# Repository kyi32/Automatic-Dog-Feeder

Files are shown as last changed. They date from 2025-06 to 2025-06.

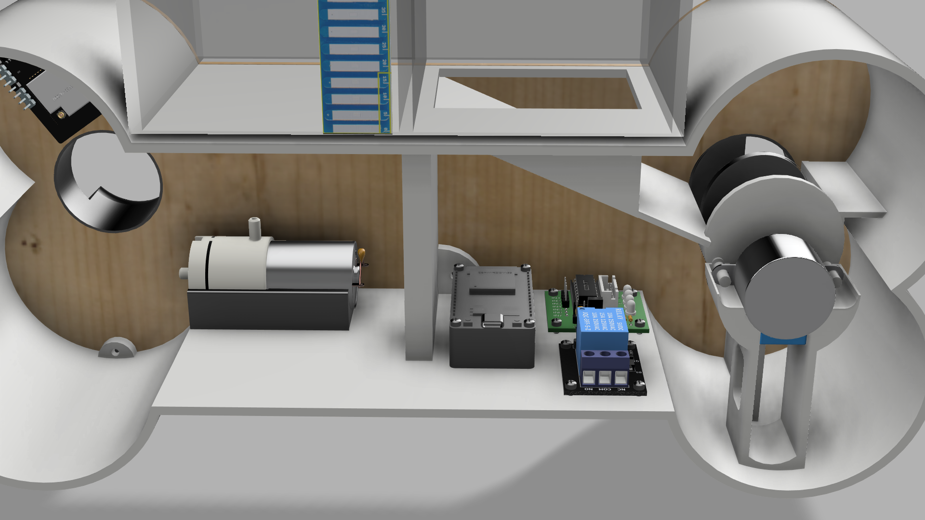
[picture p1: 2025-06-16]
assemblypetfeeder v6.png

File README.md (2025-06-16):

# Project of the Automatic Pet Feeder

## Overview
This repository contains the design files, documentation, and code for an automatic pet feeder developed by a team from the Faculty of Mechanical Engineering and Robotics at AGH. The project features a smart, app-controlled feeder with video monitoring, sensor-based food and water level detection, and customizable feeding schedules, prioritizing sustainability with recyclable materials.

## Files
### 3D Models and Drawings
- `BACK_plate.f3d`: Back plate component.
- `Bone_back_plate(autocad).pdf`: AutoCAD drawing of the back plate.
- `Bone_container_2(autocad).pdf`: AutoCAD drawing of the bone container.
- `Bone_shaped_container(autocad).pdf`: AutoCAD drawing of the bone-shaped container.
- `Bonefront_plateContainer(autocad).pdf`: AutoCAD drawing of the front plate and container.
- `Container(autocad).pdf`: AutoCAD drawing of the container.
- `Container_Drawing_v1.pdf`: Container drawing version 1.
- `Container.f3d`: Container component.
- `FOOD_SLEEVE.f3d`: Food sleeve component.
- `Front_plate.f3d`: Front plate component.
- `PetFeederAssembly.pdf`: Assembly drawing of the pet feeder.
- `PetFeederExplosion.pdf`: Exploded view of the pet feeder.
- `WATER_SLEEVE.f3d`: Water sleeve component.
- `assemblyPetfeeder_v6.png`: Assembly image version 6.
- `assemblyPetfeeder_v7.png`: Assembly image version 7.
- `assemblyPetfeeder_v8.f3z`: Assembly file version 8.
- `bone_shapeside_part-1.f3d`: Bone shape side part 1.
- `bone_shapeside_part-2.f3d`: Bone shape side part 2.
- `circuit(1).png`: Circuit diagram image 1.
- `circuit_image(1).png`: Circuit diagram image 2.
- `feedscrew_v1.f3d`: Feed screw component version 1.
- `screw(autocad).pdf`: AutoCAD drawing of the screw.

### Documentation
- `Project of the Automatic Pet Feeder.pdf`: Detailed report including project goals, morphological analysis, core design, system overview, components, software, demonstration, and future improvements.

## Project Details
- **Objective**: Simplify pet care routines with remote monitoring and control, using sustainable materials for small to medium-sized pets.
- **Features**: App-controlled food and water dispensing, live video monitoring, ultrasonic and water level sensors, customizable schedules.
- **Components**: ESP32-S3, Seeed Xiao ESP32-S3 Sense with OV2640 camera, 28BYJ-48 stepper motor, 5-12V DC water pump, HC-SR04 ultrasonic sensor, Grove water sensor, 5V 4A power supply.
- **Materials**: Plywood, biodegradable 3D filament, plexiglass.
- **Power**: 5V 4A power supply with an average current draw of ~2.565A.

## Assembly Instructions
Refer to `PetFeederAssembly.pdf` and `Project of the Automatic Pet Feeder.pdf` for step-by-step assembly instructions, including:
- Laser-cut plywood front and back plates.
- 3D-printed side cylindrical holders and container with plexiglass windows.
- Assembly using screwed and glued joints.

## Software
- **Platform**: Arduino Cloud for remote control, real-time data visualization, and scheduling.
- **Features**: Live sensor data (food/water levels), customizable schedules, manual and scheduled dispensing, camera feed via HTML site.

## Demonstration
- **Videos**: Check the prototype demonstration and assembly 3D model videos at [https://drive.google.com/drive/folders/1KkYPMTIqAwl6N05ESCOF5NJ43y_c4hTv?usp=drive_link](https://drive.google.com/drive/folders/1KkYPMTIqAwl6N05ESCOF5NJ43y_c4hTv?usp=drive_link).

## Contributors
- Ivan Rybalko
- Michal Nowicki
- KyiMin Thant

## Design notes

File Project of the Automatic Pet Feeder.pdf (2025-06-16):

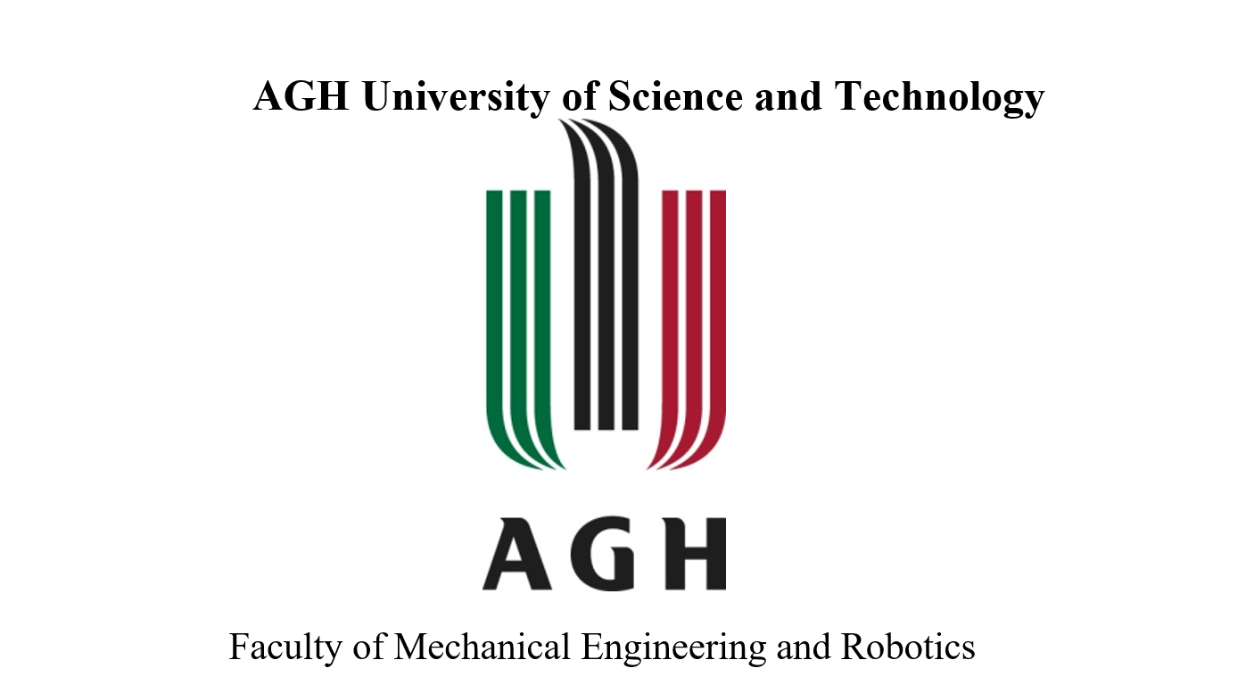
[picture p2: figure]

## Mechatronic Design

## Project of the Automatic Pet Feeder

Team members:

- Ivan Rybalko
- Michał Nowicki
- KyiMin Thant

Summary:

### 1. Introduction and Project Goals

2. Morphological Analysis
2.1 Key Differentiators from Competitors 2.2 Advantages

### 3. Core Design

3.1 Concept
3.2 Drawings

### 4. System Overview and Components

4.1 System Overview
4.2 Components
4.3 Power and Current Consumption

### 5. Software – Arduino Cloud

5.1 Working program code

### 6. System Demonstration and Functional Validation 7. Future Improvements

8. Conclusion

### 1. Introduction and Project Goals

An automatic pet feeder is a device that ensures regular feeding and water supply for a pet without direct human involvement. Our automatic pet feeder offers much more than just a basic timer-based feeder: it is an intelligent system controlled via a mobile application, equipped with video monitoring, sensor-based water and food level detection, and a fully customizable feeding schedule.

Project Goals:

- Simplify pet care routines;
- Provide remote monitoring and control;
- Prioritize sustainability using recyclable materials;

The automatic pet feeder is designed to meet the daily needs of owners of small to medium-sized pets. In modern households, pet owners often face challenges balancing their responsibilities with consistent feeding schedules, proper portion control, and real-time monitoring of their pet’s well-being. This project addresses those challenges by offering a highly automated, connected, and user-friendly solution

### 2. Morphological Analysis

Morphological Analysis Table - Design

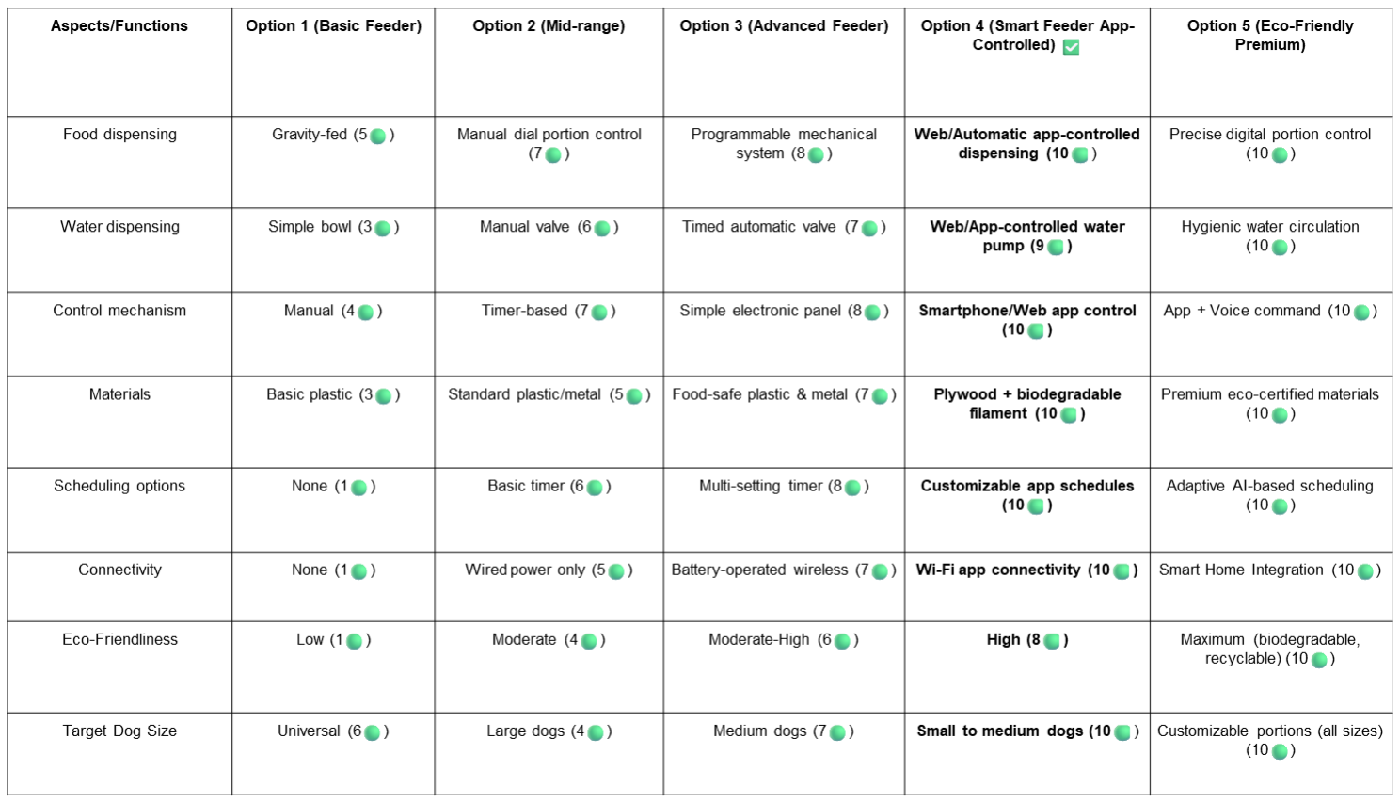
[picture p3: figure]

Functionality (1-10), Price (10-1):

Option 4 offers the best balance of functionality, technology, and value. With app-controlled food and water dispensing, customizable schedules, and Wi-Fi connectivity, it provides smart automation without the premium cost of Option 5. It also uses eco-friendly materials, making it both practical and sustainable. Overall, Option 4 is ideal for modern users seeking convenience, control, and efficiency.

Morphological Analysis Table Electronics

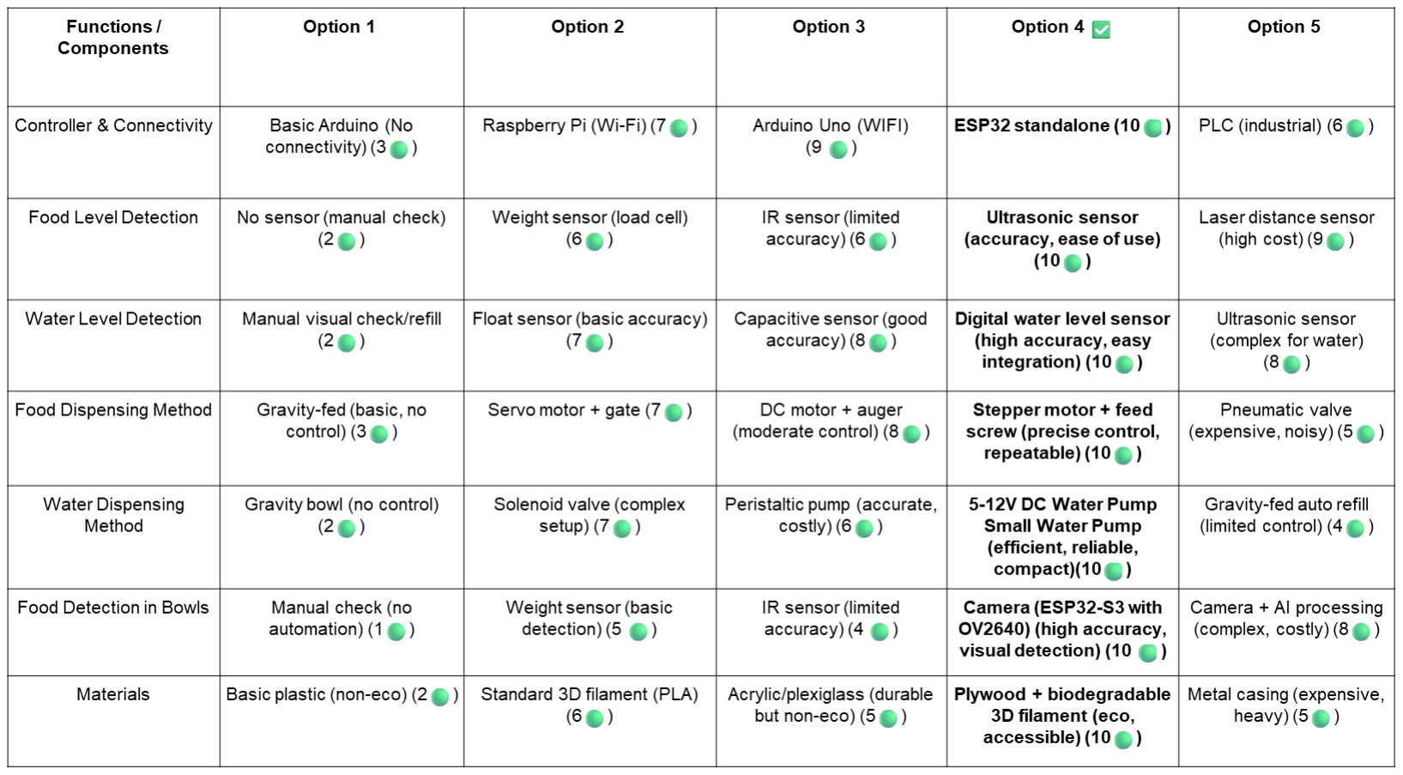
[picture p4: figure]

Functionality (1-10), Price (10-1)

Option 4 stands out by combining high-performance components with smart automation at a reasonable cost. It uses the ESP32 controller for powerful connectivity, ultrasonic sensors for accurate food and water level sensor for water level detection, and stepper motors for precise dispensing making Option 4 the most balanced and advanced choice.

Morphological Analysis Table Mechanical Components

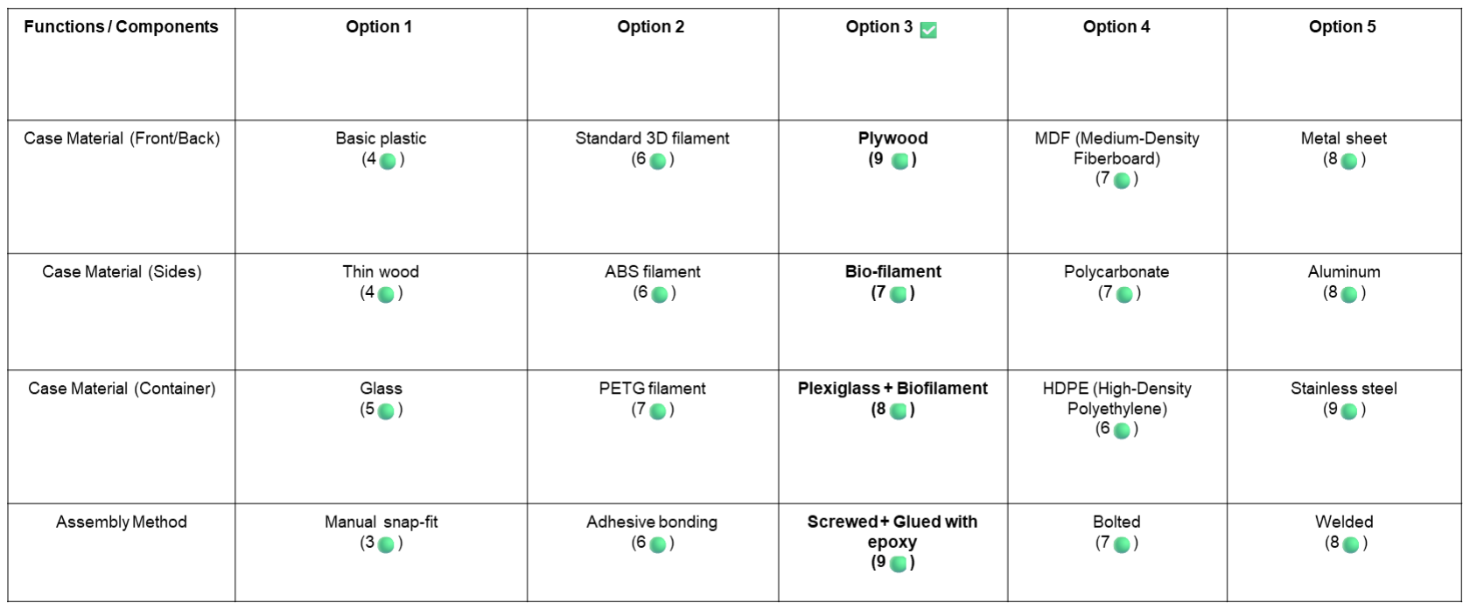
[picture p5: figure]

Functionality (1-10), Price (10-1):

Option 3 offers the most practical and well-balanced mechanical design. It uses plywood for the front/back—strong, versatile, and cost-effective—and bio-filament sides, combining durability with eco-friendliness. The container is made of 3d printed filament with plexiglass windows , offering both strength and visibility. For assembly, it uses screwed and epoxy-glued joints, ensuring strong and reliable construction. This configuration provides a solid balance of durability, sustainability, and moderate cost, making Option 3 the most efficient and well-rounded mechanical solution.

### 2.1 Key Differentiators from Competitors

The automatic pet feeder stands out in a competitive market by offering a balanced blend of intelligent automation, sustainability, and user-centric design. While many feeders on the market offer either mechanical simplicity or app-based scheduling, our solution integrates multiple high-value features into one cohesive and accessible system.

Intelligent Features

- App-Controlled Dispensing : Food delivery is fully automated and triggered through a web or smartphone app interface.
- Water Pump Control : The water pump can also be activated remotely, ensuring pets always have access to fresh water.
- Live Camera Monitoring: Unlike many feeders, ours includes live video streaming via Seeed Xiao ESP32-S3 Sense - with OV2640 camera for real-time supervision.

User-Focused Interface

- Smartphone/Web App Control : The system is designed to be intuitive and fully operable through mobile devices.
- Customizable Schedules : Feeding times and water dispensing are easily programmable, down to the minute.

Eco-Friendly and Durable Construction

- Plywood + Biodegradable Filament : The enclosure is constructed from sustainable materials, prioritizing environmental responsibility without compromising durability.
- Compact and Targeted for Household Pets: Specifically optimized for small to medium-sized dogs

### 2.2 Advantages:

Remote Control and Monitoring: The feeder can be managed entirely via a smartphone or web application. Owners can dispense food or water, view current levels, and even activate a live video stream remotely.
Custom Schedules: Feeding and hydration times can be scheduled in advance, eliminating the risk of missed meals.
Sensor-Based Precision: Ultrasonic and water level sensors provide real-time feedback on how much food and water remains, ensuring pets are never left without resources.
Eco-Friendly Construction: Physical design is made using plywood and biodegradable PLA filament, reducing plastic waste and supporting sustainable practices.

### 3. Core Design

### 3.1 Concept

Concept proposed by the team, combining the best solutions identified during the market review along with justification, pros and cons compared to other solutions, including a simplified schematic of mechanical and electronic components

Dual-Container System: The feeder features a plexiglass container divided into two compartments — one for water, one for dry food. This design enables independent dosing of each resource while providing visual feedback for users to monitor levels.

Screw-Driven Dispensing Mechanism: Dry food is dispensed using a custom-designed feed screw , which is driven by a stepper motor for high precision and repeatability. This ensures consistent portioning without clogging or overfeeding.

Water Pumping System with Relay: A 5-12V DC water pump controlled via a relay module allows for controlled water dispensing. The relay is directly actuated by the ESP32-S3 board without the need for external transistors.

Eco-Friendly Structure: The outer body is built from plywood and biodegradable 3D printed filament. Only the container uses plexiglass for visibility, making the construction sustainable and environmentally friendly.

Cloud Integration (Arduino Cloud): The system uses Arduino Cloud for real-time control and monitoring. Through a smartphone or web app, users can view food/water levels, schedule feeding times, and trigger actions remotely.

Live Video Monitoring:
An Seeed Xiao ESP32-S3 Sense - with OV2640 camera module, connected via Wi-Fi, streams video to a web browser, allowing real-time observation of the pet and food tray. The camera works independently from the ESP32-S3.

Scheduling:
Feeding and watering times can be configured with hour, minute, and date via the dashboard. These settings are stored and processed by the ESP32-S3, which executes the schedule even without an active internet connection.

### 3.2 Drawings

Below is the exploded view of our project – an automatic pet feeder. The design focuses on sustainability, functionality, and ease of manufacturing, as reflected in both the material selection and the production methods used. All parts were designed in CAD software

As illustrated in Figure 1, the feeder consists of five key components, each made from different materials and manufactured using appropriate techniques:

1. Side Cylindrical Holders Parts 1 & 2:
These parts were 3D printed using BIO-filament, a biodegradable and eco-friendly material. BIO-filament was chosen due to its minimal environmental impact and good structural properties The holders provide support for the rotation mechanism that controls the release of food.
2. Front and Back Plates Parts 3 & 4:
These elements were laser-cut from plywood. Plywood is lightweight, affordable, and sustainable, making it ideal for our needs. Laser cutting enabled us to achieve precise shapes and dimensions, including holes and slots necessary for assembly.
3. Food Container Part 6:
The container is made of 3d printed filament with plexiglass windows , chosen for its transparency, light weight, and easy machinability. Transparency allows the user to quickly check the remaining food level. The plexiglass was cut to size and manually assembled using adhesive suitable for acrylic materials.

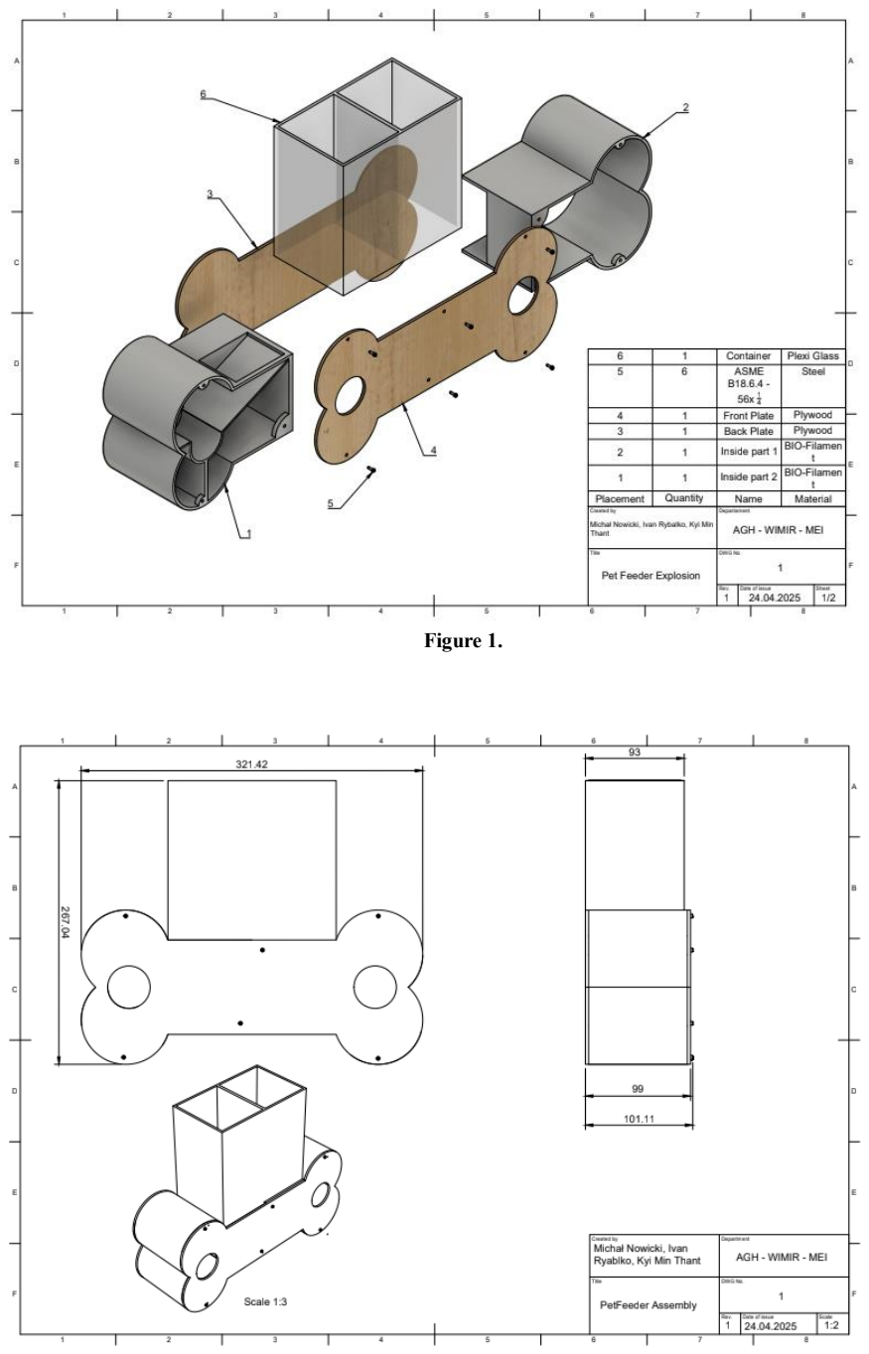
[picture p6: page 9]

Figure 1.

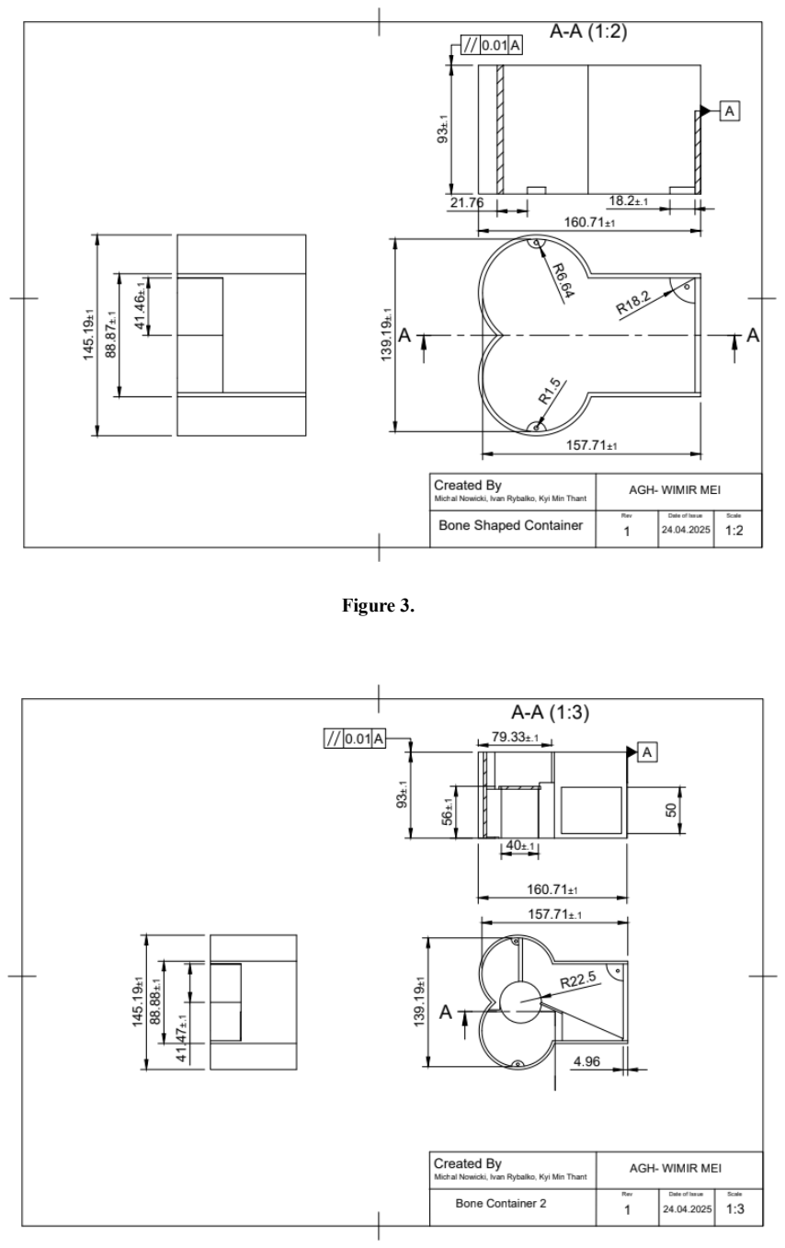
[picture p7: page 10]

Figure 2.

Figure 3.

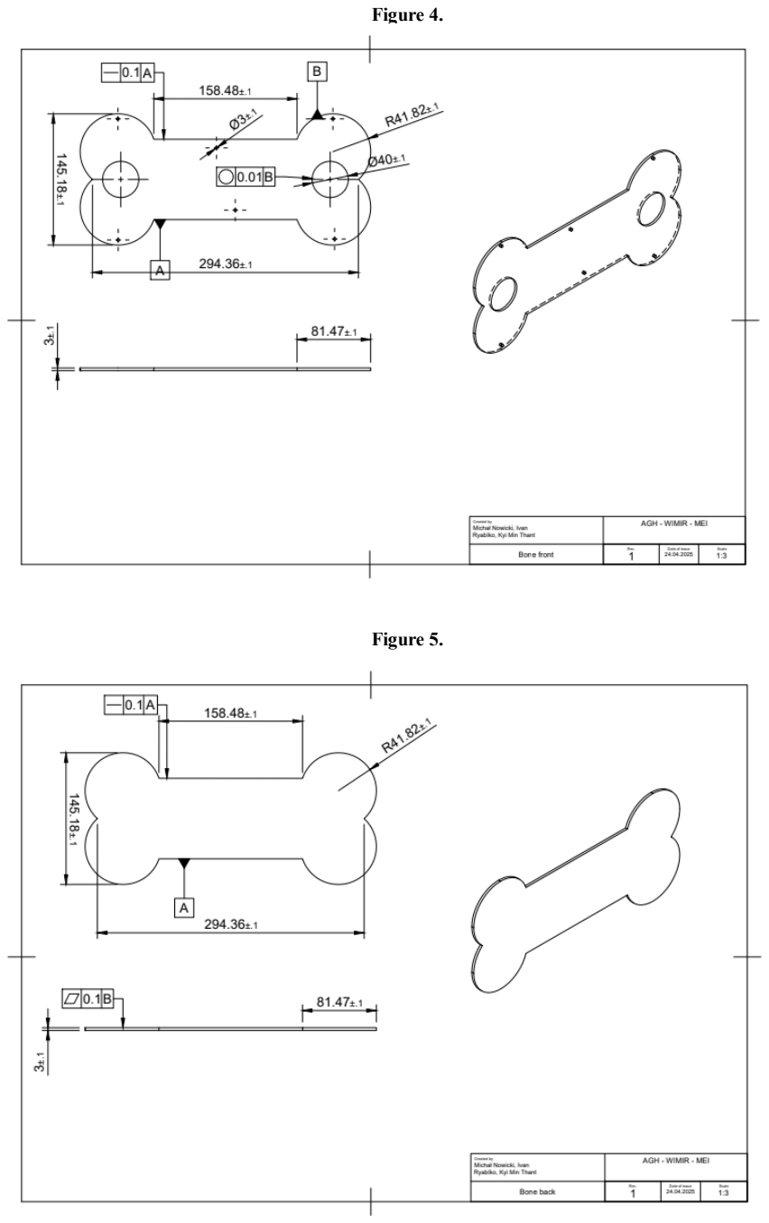
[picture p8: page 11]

Figure 4.

Figure 5.

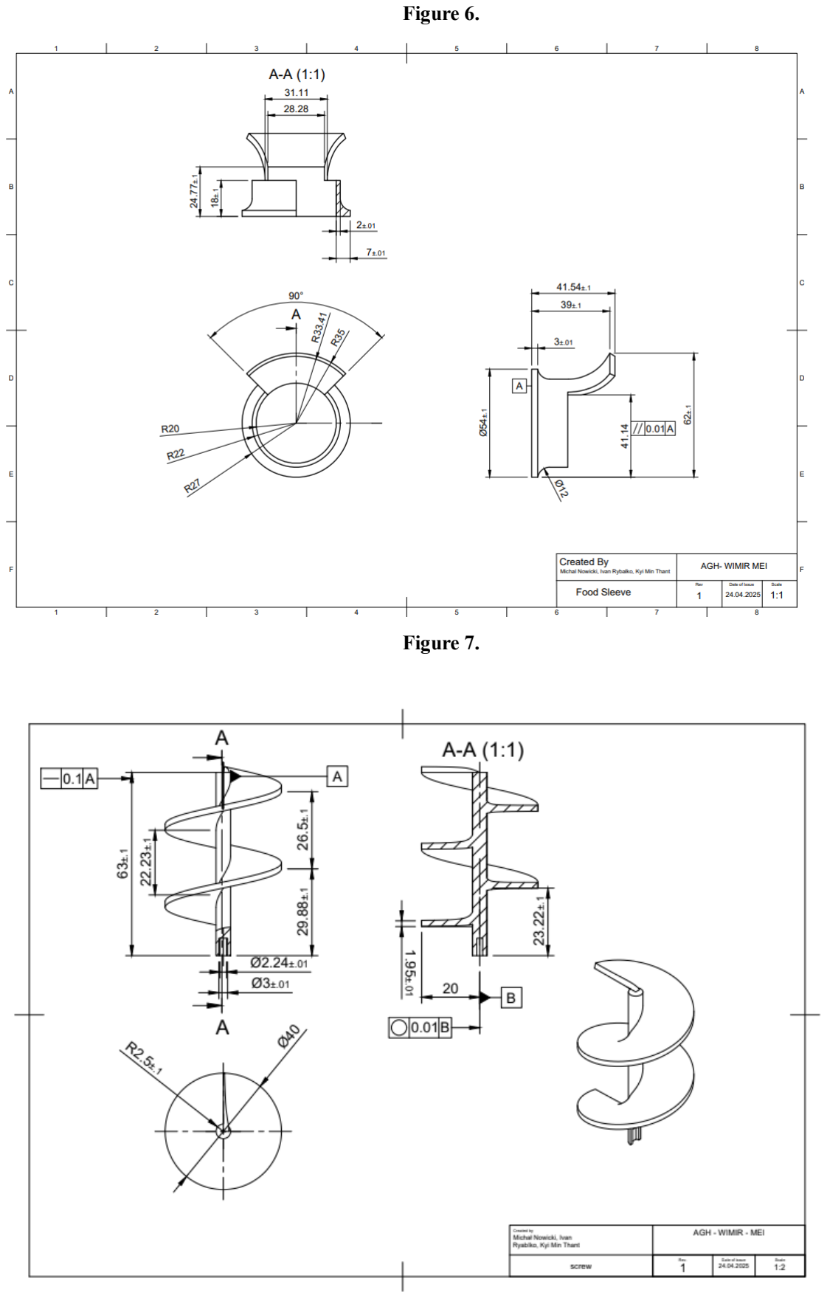
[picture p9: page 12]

Figure 6.

Figure 7.

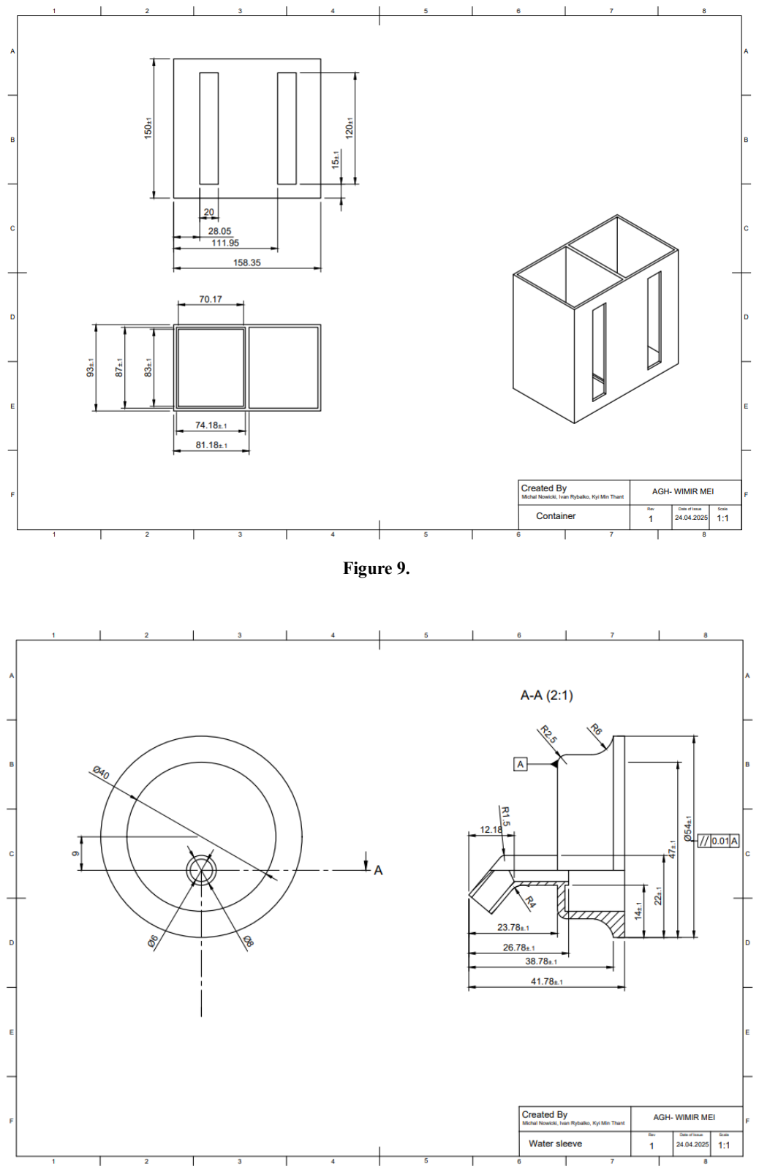
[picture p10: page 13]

Figure 8.

Figure 9.

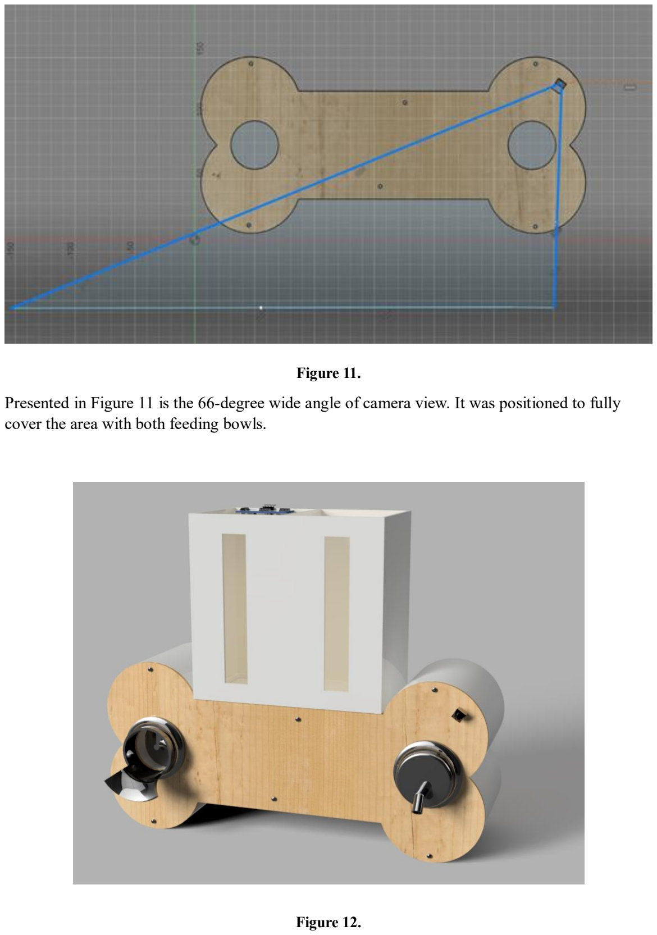
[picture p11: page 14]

Figure 10.

Figure 11.

Presented in Figure 11 is the 66-degree wide angle of camera view. It was positioned to fully cover the area with both feeding bowls.

Figure 12.

In Figure 12, the fully assembled model can be seen, created and visualized in the CAD software. This final assembly view demonstrates how all individual components fit together and provides a clear representation of the functional layout of the pet feeder.

### 4. System Overview and Components

### 4.1 System Overview

The ESP32 board controls and connects to various components,

such as the water level sensor, ultrasonic sensor, stepper motor driver and relay module.

Water level sensor is communicating via SDA(serial DATA Line) and SCL(serial clock line) pins, in reality it looks a bit different that this presented in Figure12 but its connected in correct way.

Whole system is powered by 5V 4A power supply. Estimated current draw of a system is around, 3 Amps.

Relay module is designed to be controlled directly by pins without need of additional transistors.

Seeed Xiao ESP32-S3 Sense - with OV2640 camera is not controlled via main microconstroller. Its streaming image to html site via Wifi and will be accessed by software

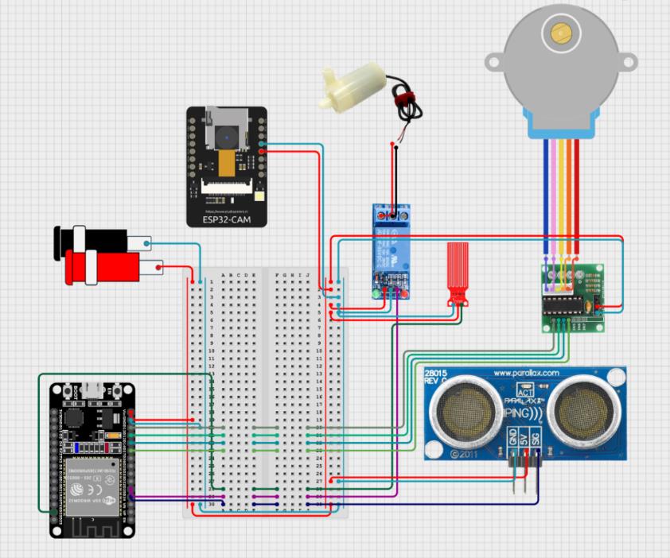
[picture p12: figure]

Figure 13.

### 4.2 Components

Component | Purpose | Justification
ESP32-S3 | Main controller | Powerful, supports Wi-Fi, BLE,
| | I2C

Seeed Xiao ESP32-S3 Sense -
with OV2640 camera | Independent camera module | Easy Wi-Fi HTML streaming
28BYJ-48 + ULN2003 driver Stepper motor for food dosing | Accurate, stable, low-power
5-12V DC Water Pump | Dispenses water | Compact and efficient
Iduino Relay Module | Controls pump power | Simple, works with ESP32
| | directly
HC-SR04 Ultrasonic Sensor | Measures remaining food | Low cost, reliable
Water Level Sensor | Measures water level | High precision, easy I2C
| | integration
5V 4A Power Supply | Powers the full system | Stable enough for ~2.5 A peak
| | load

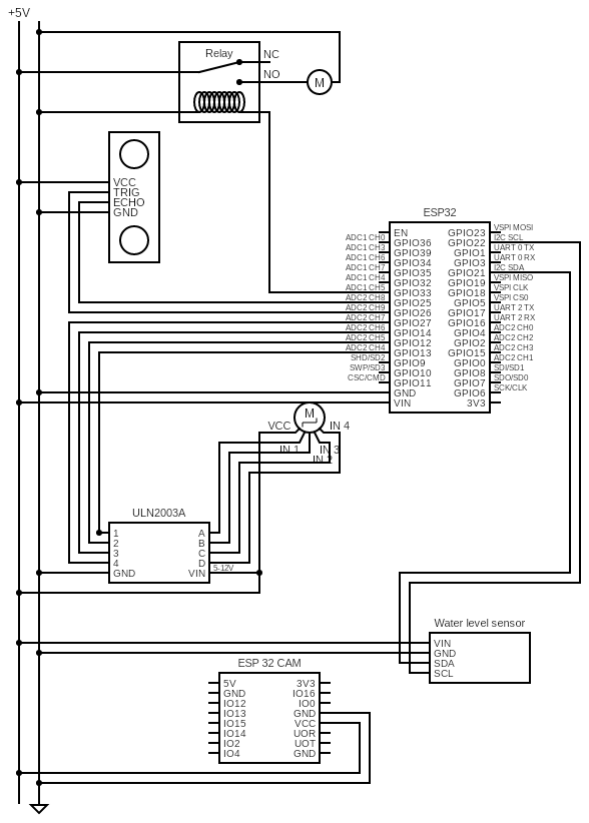
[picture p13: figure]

Figure 14

### 4.3 Power and Current Consumption

The entire system is powered by a 5V 4A switching power supply. Based on our measurements and manufacturer specifications, the average current draw is:

Component | Consumption
ESP32-S3 Sense | 200 mA
Stepper Motor + ULN2003 | 900 + 100 mA
HC-SR04 | 20 mA
Relay Module | 75 mA
Grove Water Sensor | 20 mA

Seeed Xiao ESP32-S3 Sense - with
OV2640 camera | 50 mA
5-12V DC Water Pump | 1200 mA
Total Average | ≈ 2565 mA

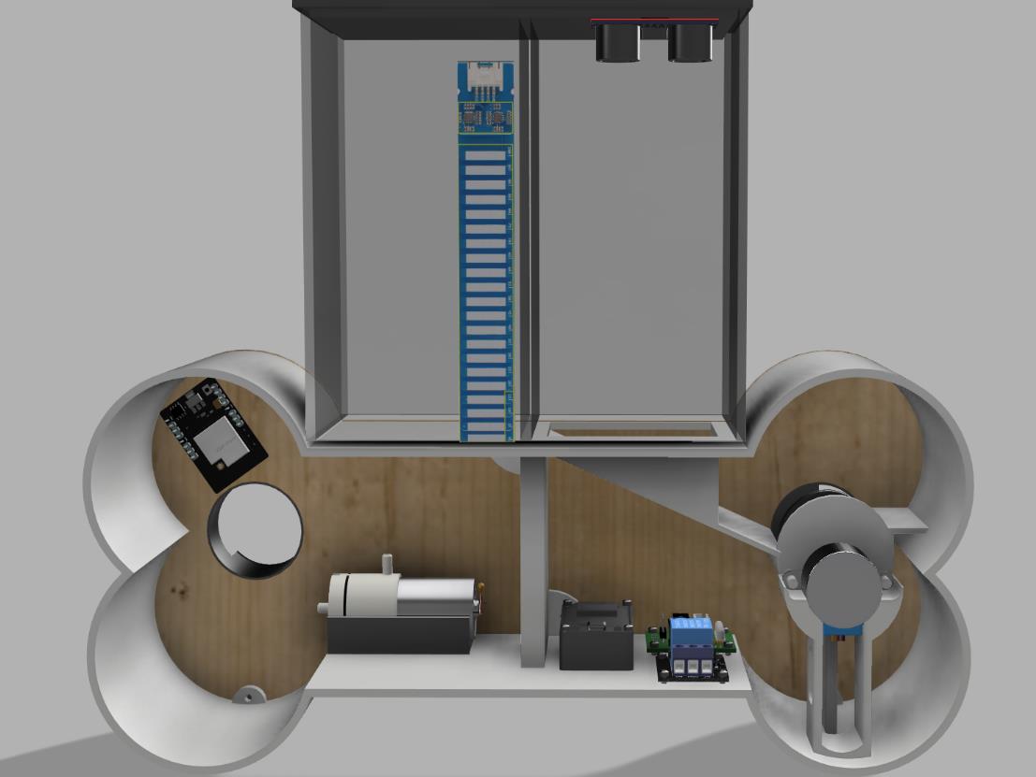
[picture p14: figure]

Figure 15

Figure 15 provides a close-up view. Wires connections are not visible to make the placement more clearly to see. All electrical connections are fully detailed in schemes Figures 13 and 14

### 5. Software – Arduino Cloud

The entire system logic of the automatic pet feeder is implemented using Arduino Cloud, an integrated IoT platform that allows remote device control, real-time data visualization, and scheduling—all accessible through a web dashboard or mobile app.

Cloud Integration Overview

Arduino Cloud handles: Device management (ESP32-S3 Sense); Live synchronization of variables; Scheduling and time-based tasks; User interface rendering (custom dashboard widgets).

System Features and Logic:

Feeding and
Water Dose | Controlled via sliders; values are read by the ESP32-S3 and trigger actuators

Level Monitoring Sensor data (HC-SR04 & Grove Water Sensor) is displayed live in
| dashboard
Schedule
Configuration | User selects hour/minute/date via time picker; stored in cloud and synced
Camera Activation | A dashboard button opens local HTML site with camera image is tunnelled
| through ngrok software to make it available publicly with https protocol

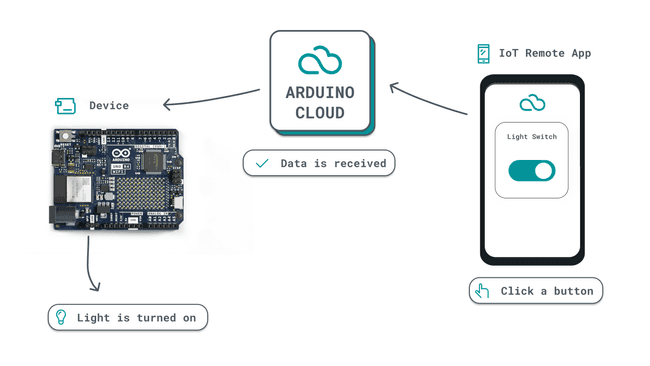
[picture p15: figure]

Figure 16

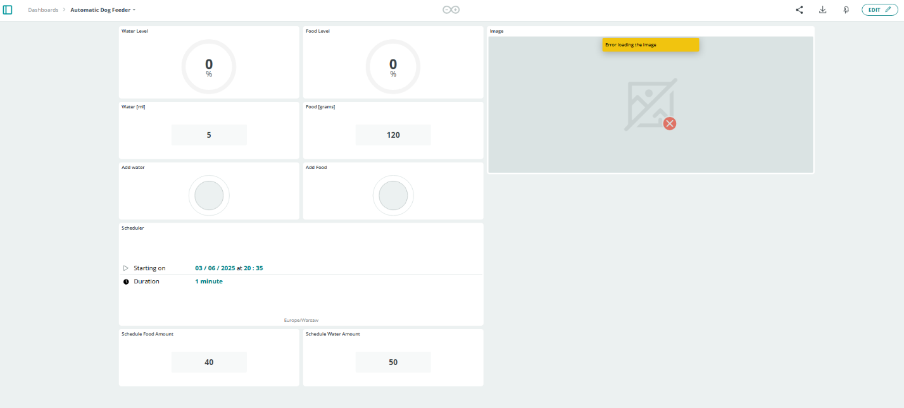
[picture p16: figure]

Figure 17

Figure 17 shows the interface concept developed in Arduino Cloud for controlling the device. This cloud-based dashboard allows real-time monitoring and remote control of key system functions, such as food dispensing, water level status. The interface is designed to be user-friendly and accessible from any internet-connected device.

Cloud Integration

The device connects to the Arduino IoT Cloud using Wi-Fi credentials and unique device keys. Several cloud variables are defined to report water and food levels and to receive user commands and schedules. The initProperties() function registers these variables, enabling seamless communication between the device and cloud dashboard.

Sensor Inputs

Two types of sensors provide environmental feedback:

- Ultrasonic Sensor measures the distance to the food surface, converting it into a percentage with calibration to account for empty bin offset.
- Grove I²C Water Sensor detects the number of “wet” pads across two sections, calculating the water level as a percentage based on active segments.

Actuation

The system dispenses:

- Water via a relay-controlled pump, with timing based on a fixed flow rate (PUMP_FLOW_ML_PER_MIN).
- Food using a stepper motor, where the number of steps is proportional to the required grams (FOOD_PER_REV_G).

Safety and Scheduling

Manual activation is throttled by a 10-second delay to prevent overuse. Additionally, a cloud-based schedule trigger can initiate both food and water dispensing, enabling automated daily routines

### 5.1 Working program code

#include <ArduinoIoTCloud.h> #include <Arduino_ConnectionHandler.h> #include <WiFi.h>

#include <Wire.h>

#include <AccelStepper.h>

const char SSID[] | = "UPC3216837";
const char PASS[] | = "WifiPass";
const char THING_ID[] | = "#############################";
const char DEVICE_LOGIN_NAME[] = "###########################";
const char DEVICE_KEY[] | = "##############################;
WiFiConnectionHandler ArduinoIoTPreferredConnection(SSID, PASS);
#define STEPPER_IN1 | 13

#define STEPPER_IN2 | 12

#define STEPPER_IN3 | 14

#define STEPPER_IN4 | 27

#define TRIG_PIN | 26

#define ECHO_PIN | 25

#define RELAY_PIN | 33

#define I2C_SDA | 21

#define I2C_SCL | 22

const float | PUMP_FLOW_ML_PER_MIN = 1200.0;
const float | FOOD_PER_REV_G | = 20.0;
const float | FOOD_BIN_HEIGHT_CM | = 12.5;
const unsigned long SAFETY_DELAY | = 10000;
const float | FOOD_EMPTY_RAW_PCT | = 7.0;
const float | FOOD_FULL_RANGE_PCT | = 100.0 - FOOD_EMPTY_RAW_PCT;
const uint8_t WATER_LOW_ADDR | = 0x77; | // low-section (8 pads)
const uint8_t WATER_HIGH_ADDR = 0x78; | // high-section (12 pads)
const uint8_t TOUCH_THRESHOLD = 100; | // default threshold for “wet”
float | waterLevelPct, foodLevelPct;
int | waterAmountInput, foodAmountInput;
bool | waterButton, foodButton;
int | scheduleWaterAmount, scheduleFoodAmount;
CloudSchedule | waterScheduleTrigger;

AccelStepper stepper(AccelStepper::HALF4WIRE, STEPPER_IN1, STEPPER_IN3,
STEPPER_IN2, STEPPER_IN4);

unsigned long lastWaterMillis = 0, lastFoodMillis = 0;
bool prevWaterActive = false; void initProperties();
void onWaterButtonChange(); void onFoodButtonChange(); void deployWater(int ml);
void deployFood(int g);
void readI2CWaterSensor(); void setup() {

Serial.begin(115200);
delay(500);
pinMode(TRIG_PIN, OUTPUT); pinMode(ECHO_PIN, INPUT);
pinMode(RELAY_PIN, OUTPUT); digitalWrite(RELAY_PIN, LOW); Wire.begin(I2C_SDA, I2C_SCL); stepper.setMaxSpeed(1000); stepper.setAcceleration(150);
initProperties();

ArduinoCloud.begin(ArduinoIoTPreferredConnection); setDebugMessageLevel(2);
ArduinoCloud.printDebugInfo();
}

void loop() {
ArduinoCloud.update();

static unsigned long lastSensMillis = 0; if (millis() - lastSensMillis > 1000) { lastSensMillis = millis(); readI2CWaterSensor();

digitalWrite(TRIG_PIN, LOW); delayMicroseconds(2);
digitalWrite(TRIG_PIN, HIGH); delayMicroseconds(10);
digitalWrite(TRIG_PIN, LOW);
long dur = pulseIn(ECHO_PIN, HIGH);
float dist = dur * 0.034 / 2.0; // measured distance (cm)
float levelRawCm = FOOD_BIN_HEIGHT_CM - dist;
float rawPct = constrain((levelRawCm / FOOD_BIN_HEIGHT_CM) * 100.0, 0.0, 100.0);
float adjusted | = rawPct - FOOD_EMPTY_RAW_PCT;
float scaledPct | = adjusted * (100.0 / FOOD_FULL_RANGE_PCT);
foodLevelPct | = constrain(scaledPct, 0.0, 100.0);
}
if (waterButton && millis() - lastWaterMillis > SAFETY_DELAY) { deployWater(waterAmountInput);
lastWaterMillis = millis();
}
waterButton = false;
if (foodButton && millis() - lastFoodMillis > SAFETY_DELAY) { deployFood(foodAmountInput);
lastFoodMillis = millis();
}
foodButton = false;
bool nowWaterActive = waterScheduleTrigger.isActive();
if (nowWaterActive && !prevWaterActive) {

Serial.println("Scheduler activated: deploying scheduled water AND food");
deployWater(scheduleWaterAmount); deployFood(scheduleFoodAmount);
}
prevWaterActive = nowWaterActive;
}
void initProperties() {
ArduinoCloud.setBoardId(DEVICE_LOGIN_NAME); ArduinoCloud.setSecretDeviceKey(DEVICE_KEY);

ArduinoCloud.setThingId(THING_ID); ArduinoCloud.addProperty(waterLevelPct, READ, ON_CHANGE, NULL); ArduinoCloud.addProperty(foodLevelPct, READ, ON_CHANGE, NULL); ArduinoCloud.addProperty(waterAmountInput, READWRITE, ON_CHANGE, NULL);
ArduinoCloud.addProperty(foodAmountInput, | READWRITE, ON_CHANGE, NULL);
ArduinoCloud.addProperty(waterButton, | READWRITE, ON_CHANGE,
onWaterButtonChange);
ArduinoCloud.addProperty(foodButton, | READWRITE, ON_CHANGE,
onFoodButtonChange);
ArduinoCloud.addProperty(scheduleWaterAmount, READWRITE, ON_CHANGE, NULL); ArduinoCloud.addProperty(scheduleFoodAmount, READWRITE, ON_CHANGE, NULL); ArduinoCloud.addProperty(waterScheduleTrigger, READWRITE, ON_CHANGE, NULL); }

void onWaterButtonChange() {
if (waterButton && millis() - lastWaterMillis > SAFETY_DELAY) { deployWater(waterAmountInput);
lastWaterMillis = millis();
}
waterButton = false;
}

void onFoodButtonChange() {
if (foodButton && millis() - lastFoodMillis > SAFETY_DELAY) { deployFood(foodAmountInput);
lastFoodMillis = millis();
}
foodButton = false;
}

void readI2CWaterSensor() {
uint8_t low_data[8], high_data[12]; uint32_t mask = 0;

Wire.beginTransmission(WATER_LOW_ADDR); Wire.endTransmission();
Wire.requestFrom(WATER_LOW_ADDR, (uint8_t)8);
for (int i = 0; i < 8 && Wire.available(); i++) { low_data[i] = Wire.read();
if (low_data[i] > TOUCH_THRESHOLD) mask |= 1UL << i; }
Wire.beginTransmission(WATER_HIGH_ADDR); Wire.endTransmission();
Wire.requestFrom(WATER_HIGH_ADDR, (uint8_t)12);
for (int i = 0; i < 12 && Wire.available(); i++) { high_data[i] = Wire.read();
if (high_data[i] > TOUCH_THRESHOLD) mask |= 1UL << (8 + i); }
uint32_t touch = mask;
uint8_t sections = 0;
while (touch & 0x01) {
sections++;
touch >>= 1;
}
waterLevelPct = constrain(sections * 5.0, 0.0, 100.0); }

void deployWater(int ml) {
unsigned long onTime = (unsigned long)(ml / PUMP_FLOW_ML_PER_MIN * 60000.0);
digitalWrite(RELAY_PIN, HIGH);
delay(onTime);
digitalWrite(RELAY_PIN, LOW); }

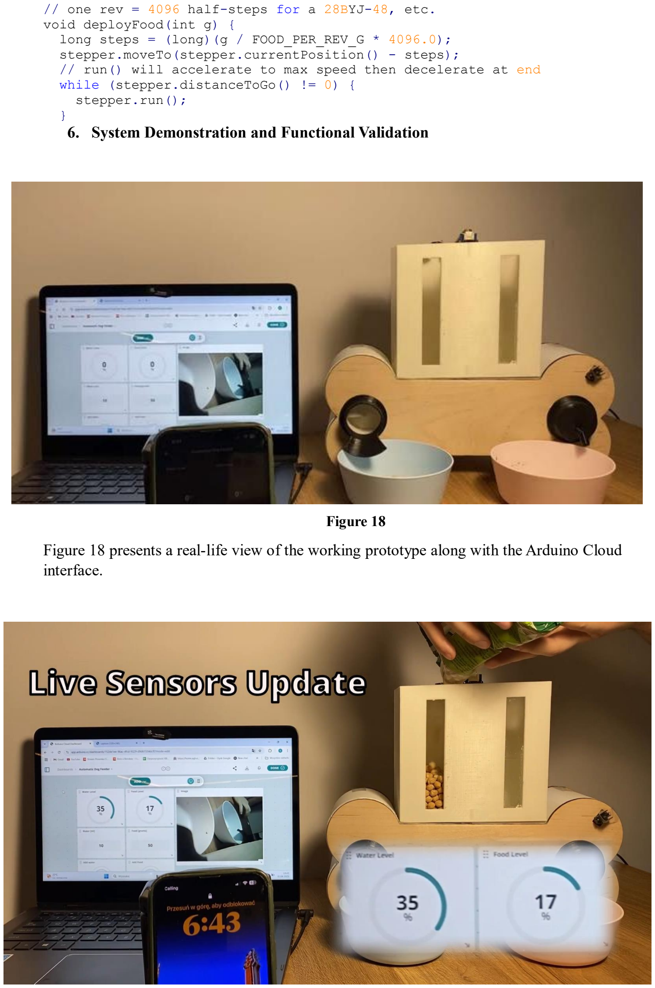
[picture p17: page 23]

// one rev = 4096 half-steps for a 28BYJ-48, etc. void deployFood(int g) {
long steps = (long)(g / FOOD_PER_REV_G * 4096.0); stepper.moveTo(stepper.currentPosition() - steps);
// run() will accelerate to max speed then decelerate at end while (stepper.distanceToGo() != 0) {
stepper.run();
}

### 6. System Demonstration and Functional Validation

Figure 18

Figure 18 presents a real-life view of the working prototype along with the Arduino Cloud interface.

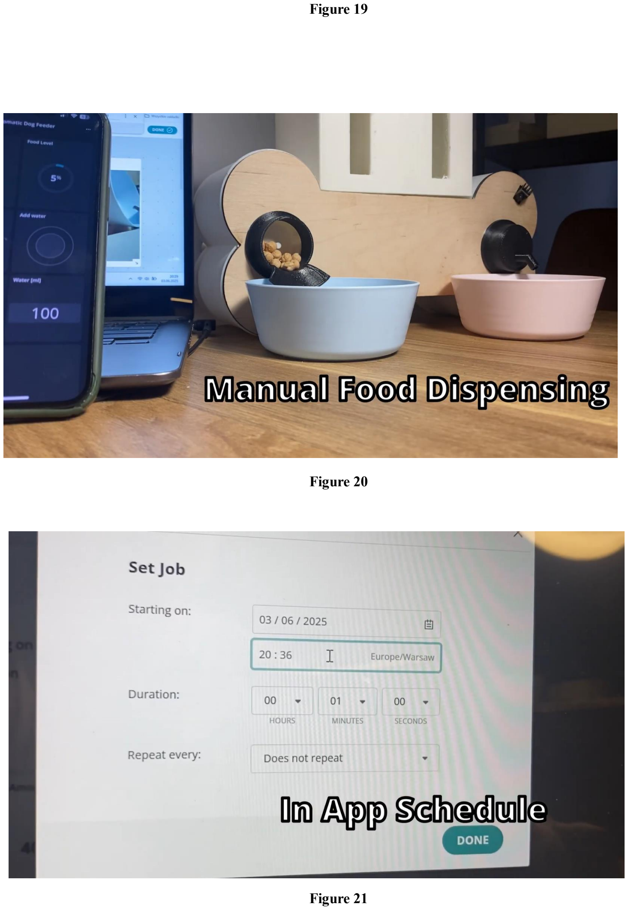
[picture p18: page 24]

Figure 19

Figure 20

Figure 21

Figures 19, 20, 21 demonstrate the working prototype during various stages of operation. For clarity, these images showcase that all previously mentioned functions — including automated food and water dispensing, water level and food level monitoring and camera feedback — operate exactly as intended. This visual documentation confirms the successful implementation and integration of both the hardware and software components.

### 7. Future Improvements

- Physical Control Buttons:
Adding physical buttons on the device would offer direct control without needing to access the online interface, improving accessibility and usability.
- Food Density Adjustment:
Introducing a feature that allows the user to input or select the type and density of pet food would improve the accuracy of portioning by weight rather than volume, making the system more precise for various food types.
- Own Domain and Cloud Hosting:
Hosting the control interface and live camera feed on a custom domain would provide easier and more reliable access. This would allow the user to manage the feeder remotely through a dedicated web application, improving scalability

### 8. Conclusion:

The presented project successfully demonstrates the design, construction, and testing of a automatic pet feeder. Through a combination of CAD modeling, 3D printing, laser cutting, and embedded electronics, the team developed a fully functional prototype capable of automated food and water dispensing, real-time monitoring, and remote control.

As shown in Figures 19–21, the system performs reliably under real conditions. The integration with Arduino Cloud enables intuitive control via a web-based dashboard and mobile devices, offering features such as food and water dispensing, water level and food level monitoring and camera feedback.

The physical prototype, combined with software automation, validates all design goals: sustainability, ease of use, and functionality

Overall, the project proves to be a scalable, practical, and eco-conscious solution for modern pet owners, combining smart-home features with mechatronic engineering principles.

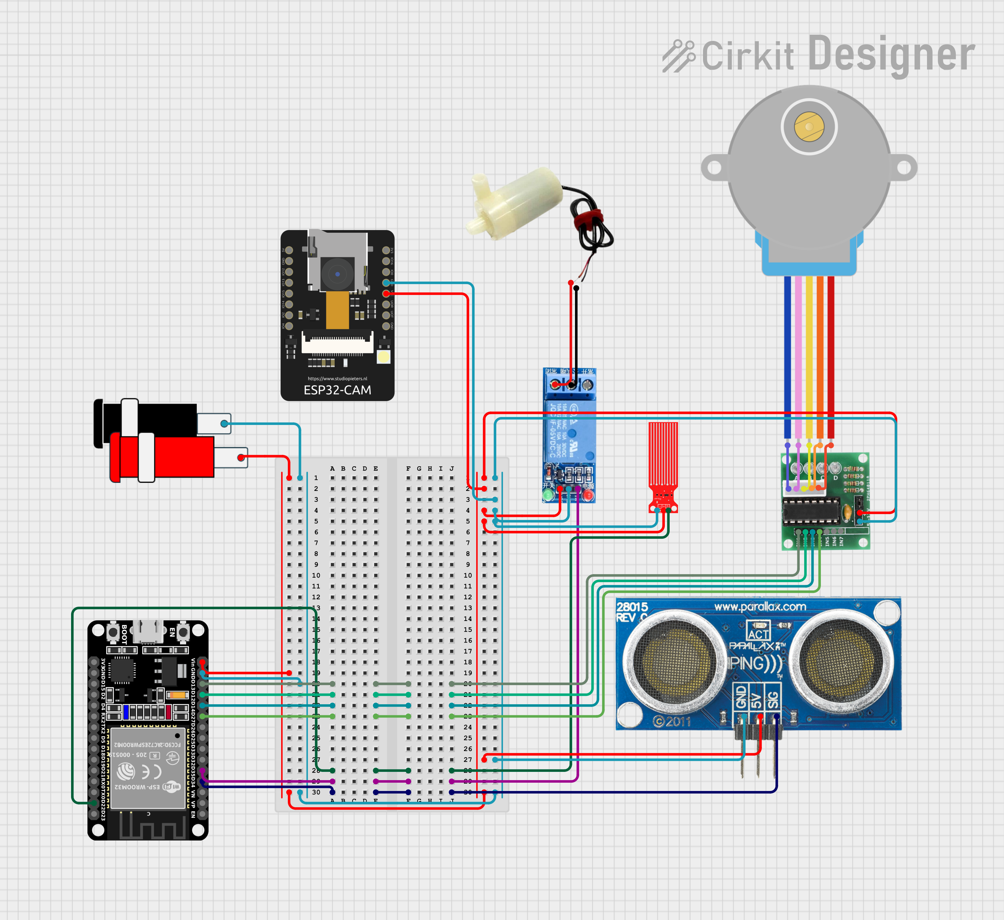
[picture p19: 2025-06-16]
circuit_image (1).png

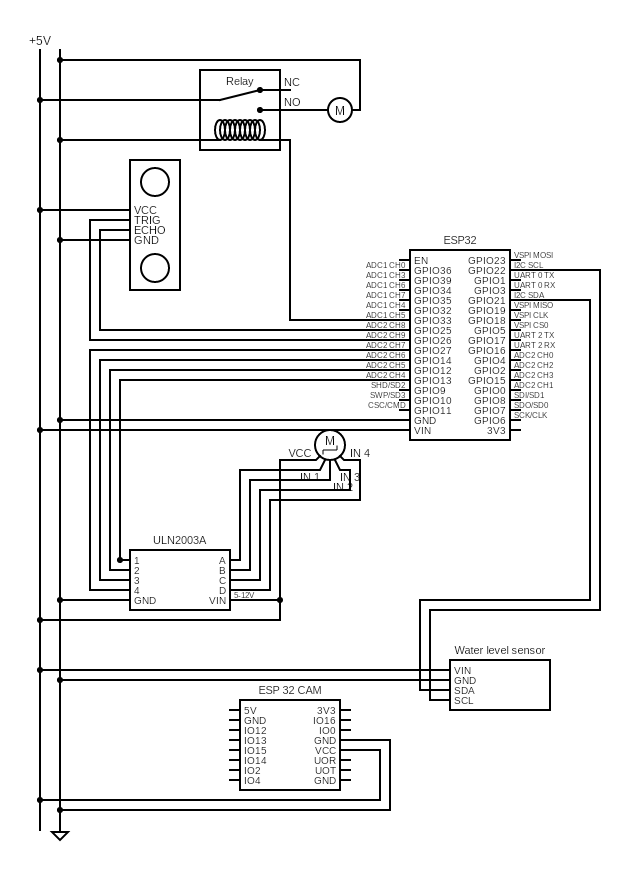
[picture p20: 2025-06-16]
circuit (1).png

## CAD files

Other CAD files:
BACK plate.f3d
Container.f3d
FOOD SLEEVE.f3d
Front plate.f3d
WATER SLEEVE.f3d
bone shape(side part-1).f3d
bone shape(side part-2).f3d
feedscrew v1.f3d

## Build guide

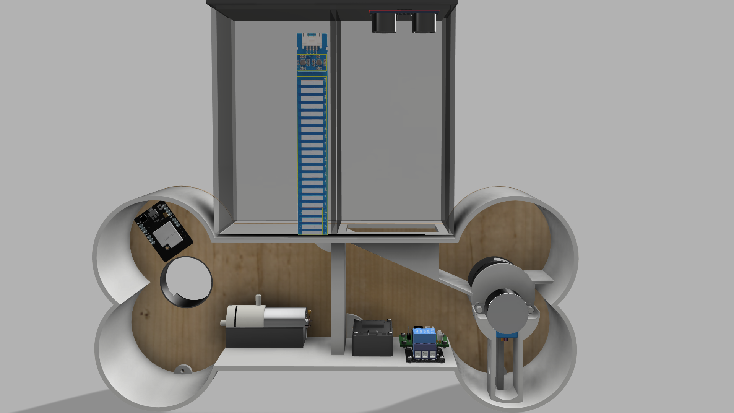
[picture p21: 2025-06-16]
assemblypetfeeder v7.png

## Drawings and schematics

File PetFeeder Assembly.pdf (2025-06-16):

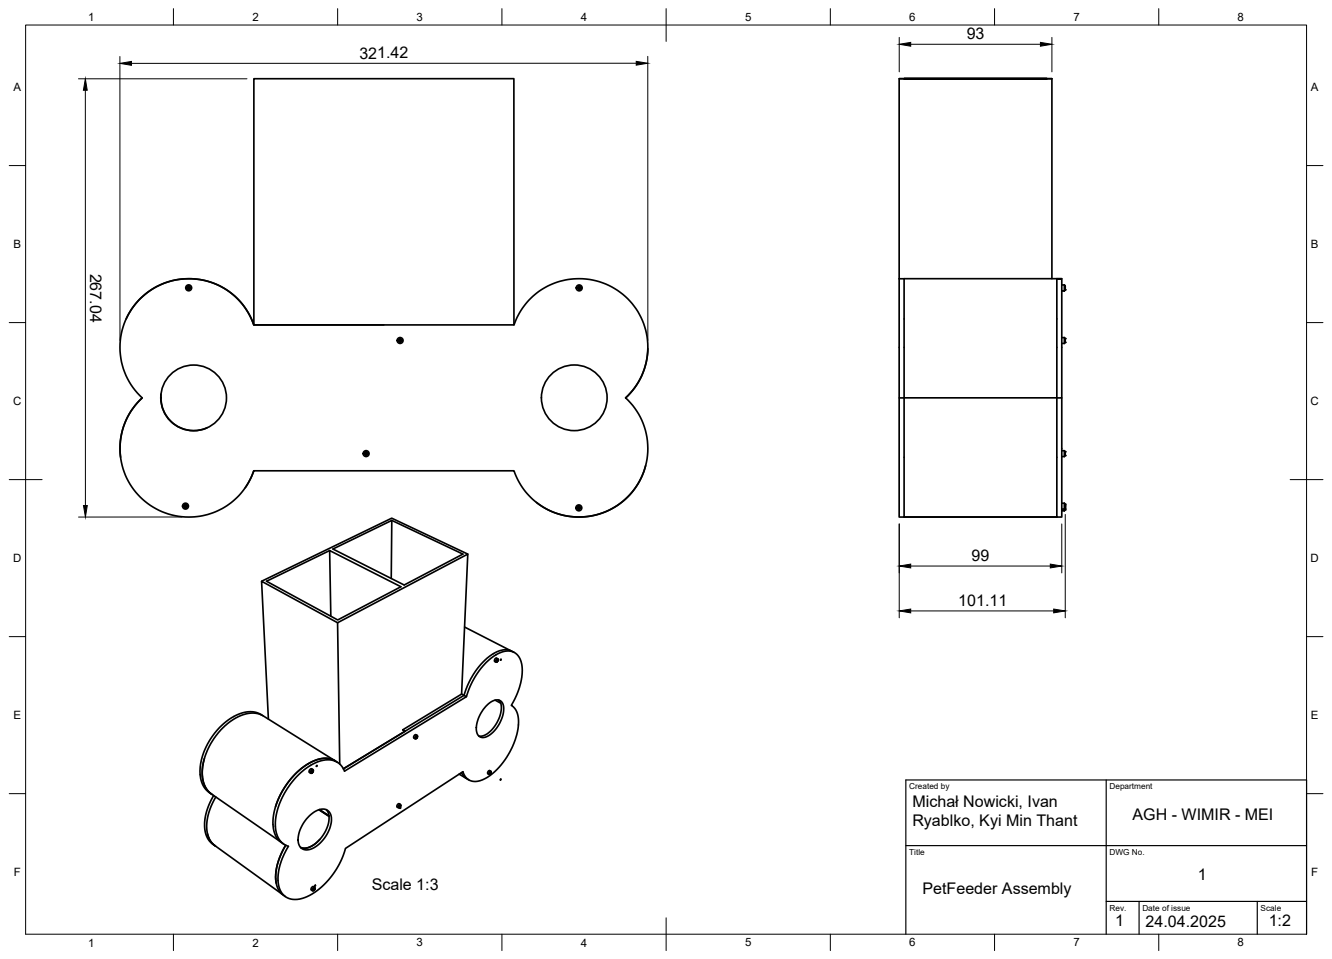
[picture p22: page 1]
Scale 1:3; Title; DWG No.; Rev.; Date of issue; Scale; PetFeeder Assembly

Created by Michał Nowicki, Ivan Ryablko, Kyi Min Thant | Department AGH - WIMIR - MEI

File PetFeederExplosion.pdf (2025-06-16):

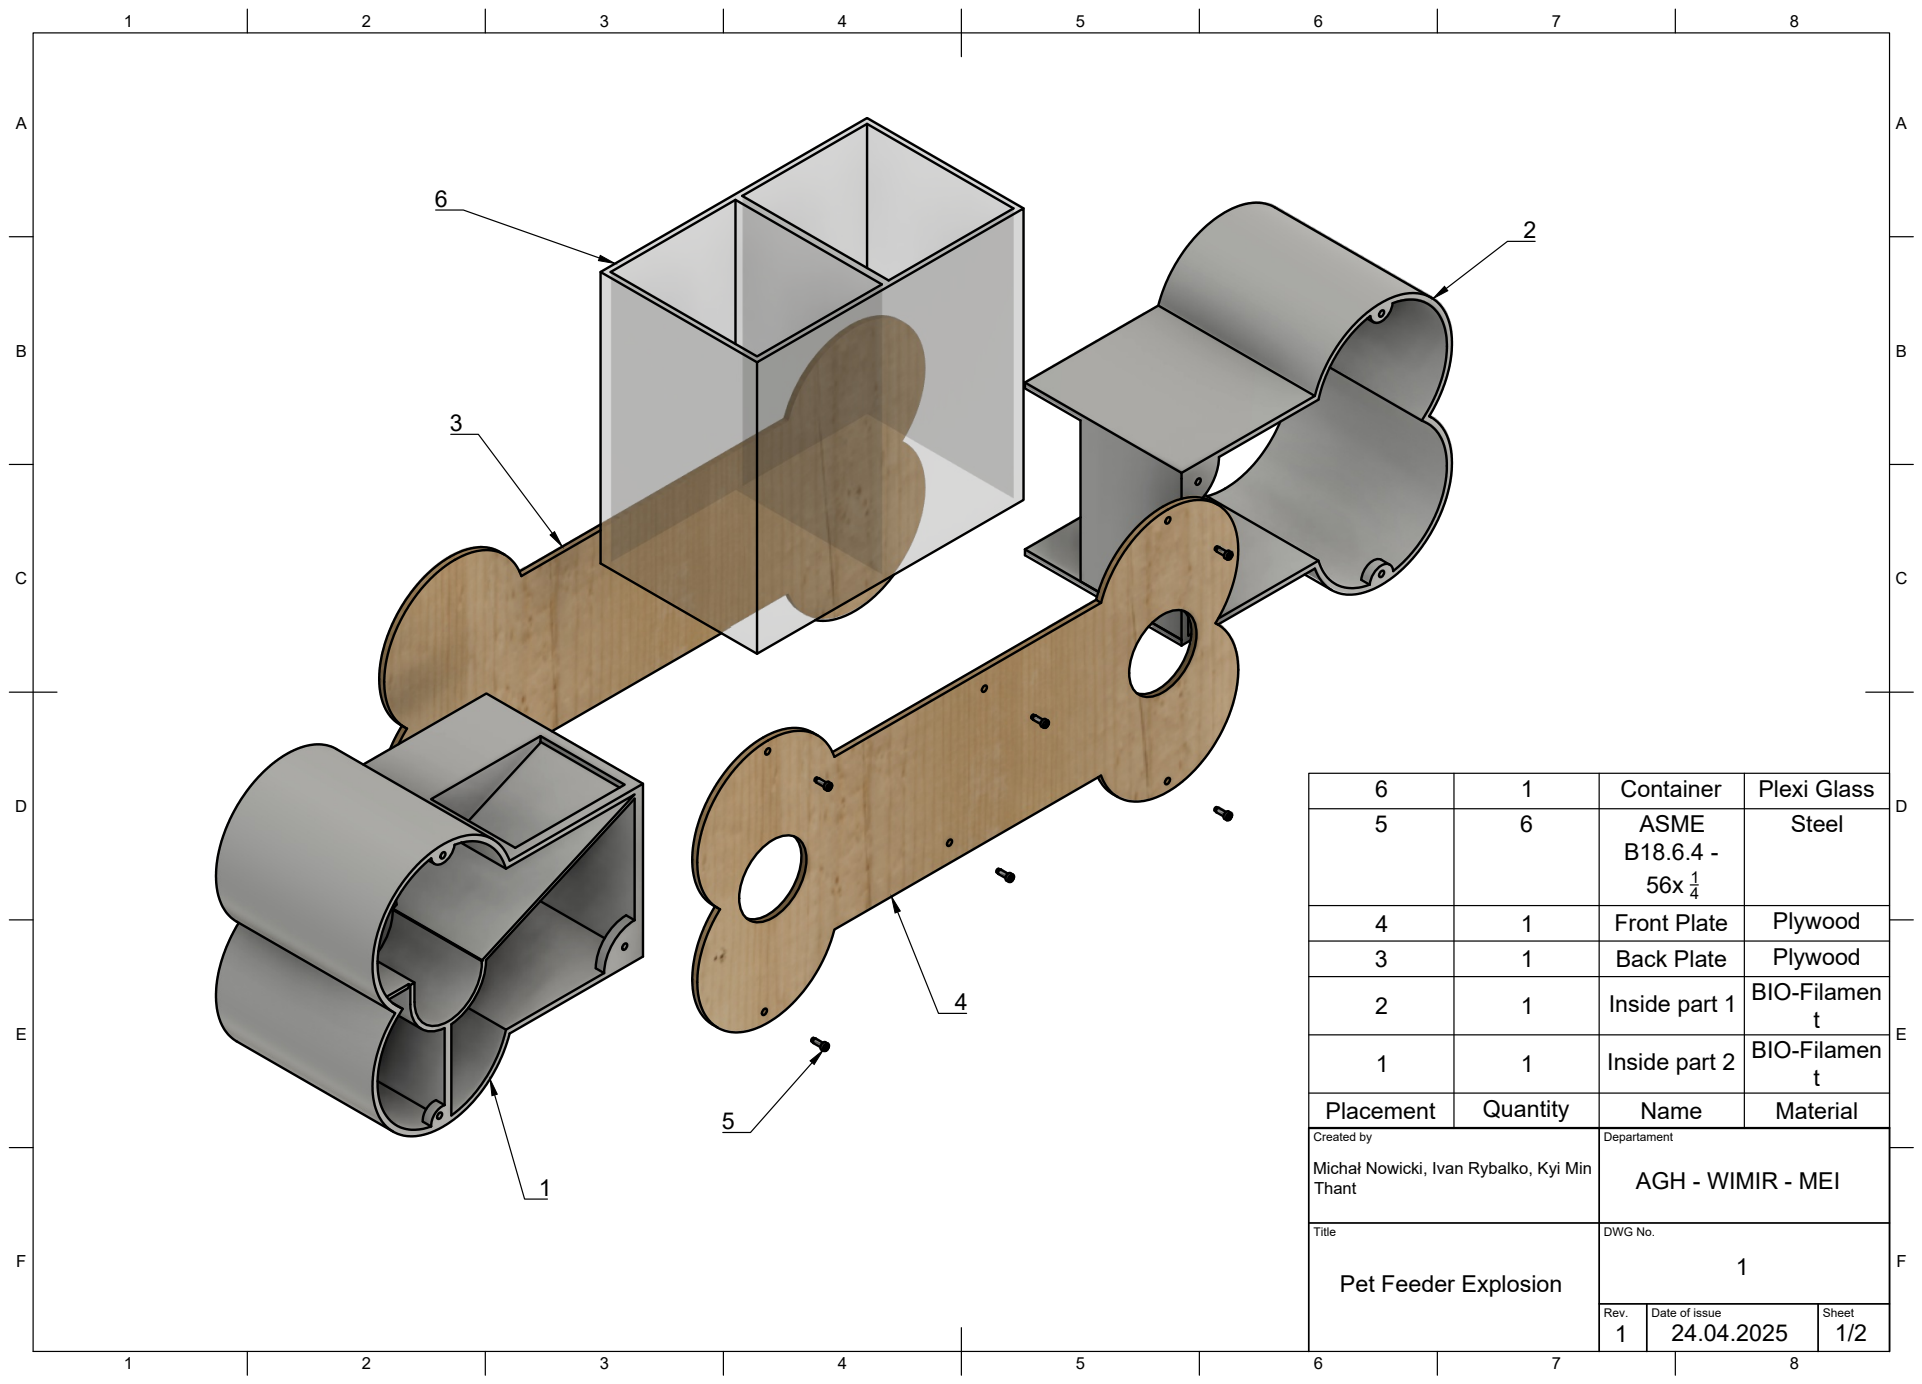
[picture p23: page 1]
8 BCDEF; ABCDEF; Steel 6; Container; Plexi Glass 5; Created by; Departament; Title; DWG No.; Rev.; Date of issue; Sheet; Thant; AGH - WIMIR - MEI; Pet Feeder Explosion

Placement | Quantity 6 1 1 1 1 | Inside part 2 Inside part 1 Front Plate Back Plate ASME Name | BIO-Filamen t 2 BIO-Filamen t 3 Plywood 4 Plywood 5 Material 1

Michał Nowicki, Ivan Rybalko, Kyi Min

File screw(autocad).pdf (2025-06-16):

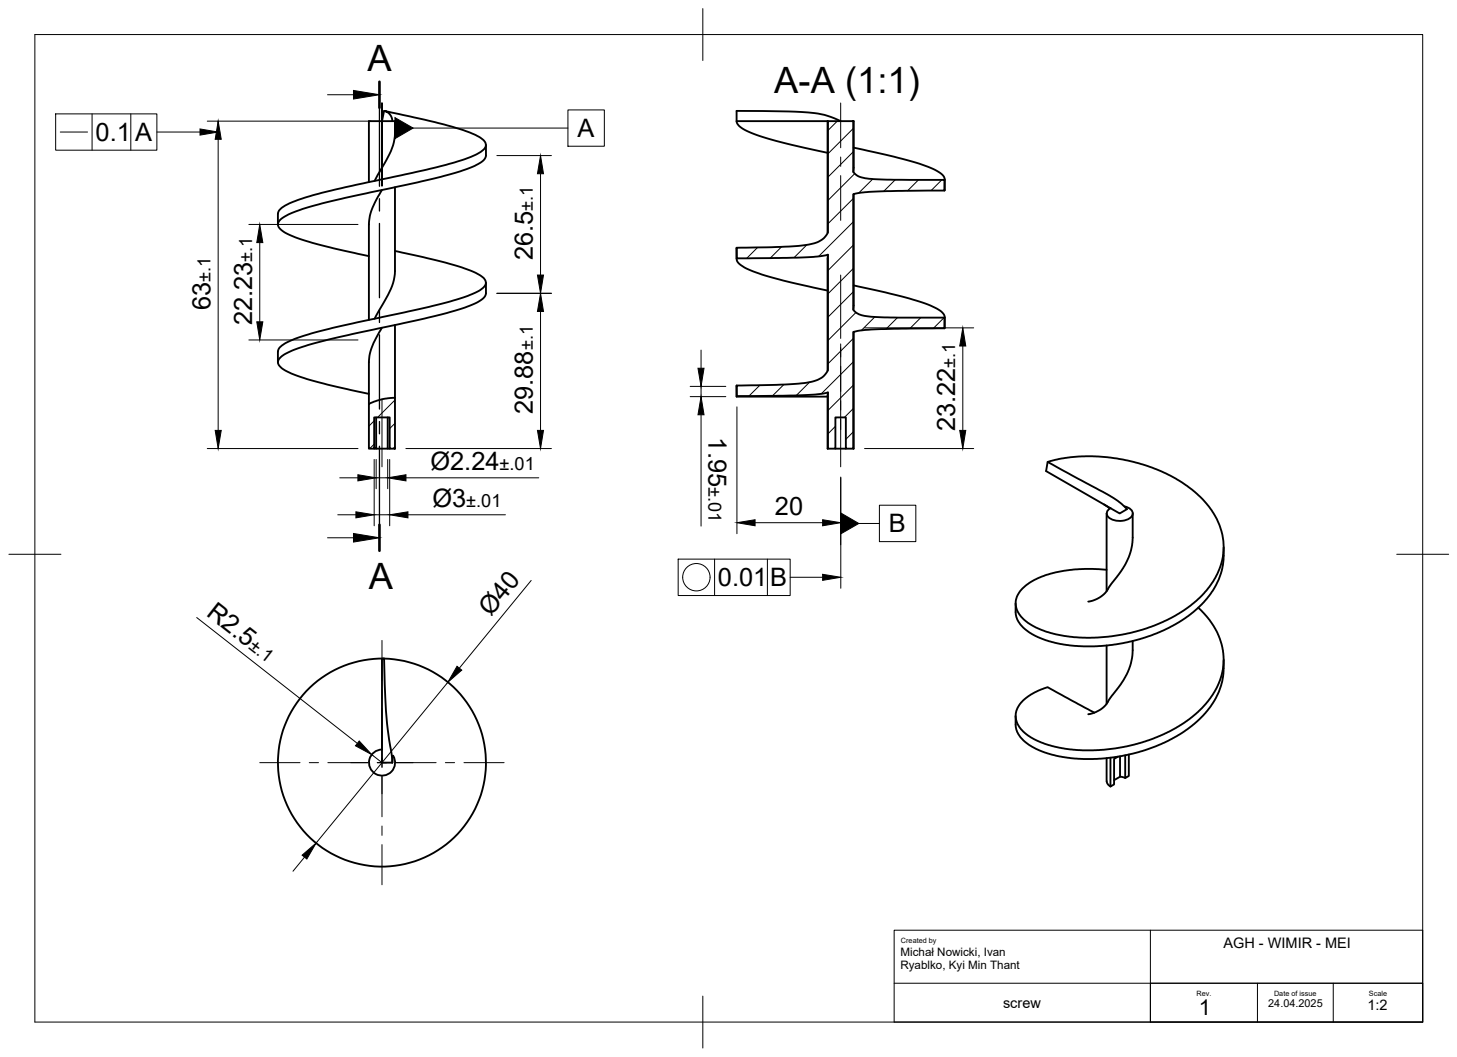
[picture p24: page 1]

Created by Michał Nowicki, Ivan Ryablko, Kyi Min Thant | AGH - WIMIR - MEI Rev. 1

screw | | Date of issue 24.04.2025 | Scale 1:2

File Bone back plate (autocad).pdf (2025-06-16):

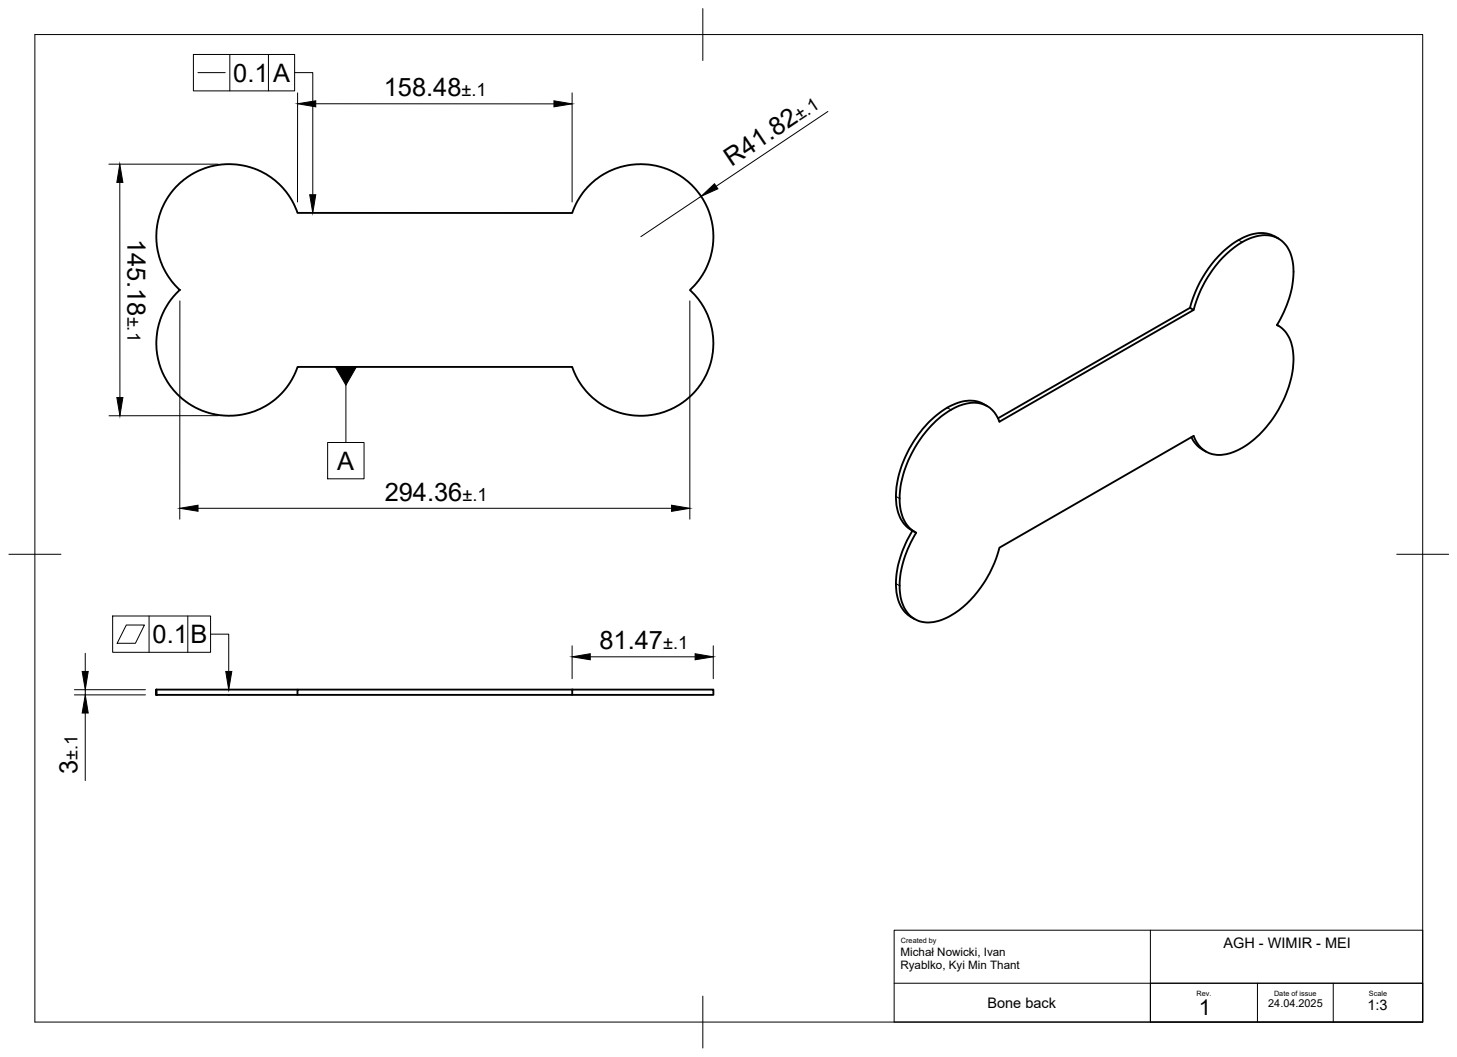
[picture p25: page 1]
Scale 1:3 145.18±.1

Created by Michał Nowicki, Ivan Ryablko, Kyi Min Thant | AGH - WIMIR - MEI Rev. 1

Bone back | | Date of issue 24.04.2025

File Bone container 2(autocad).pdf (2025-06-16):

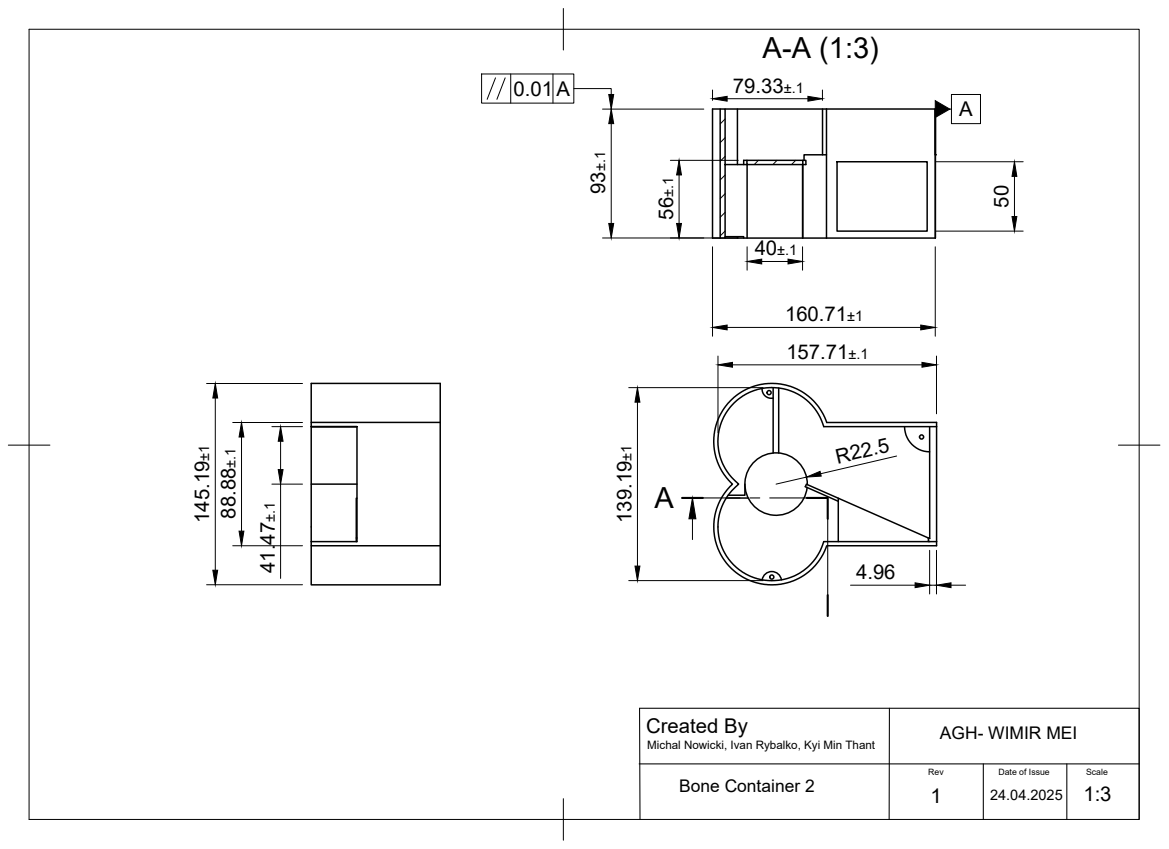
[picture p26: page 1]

Created By Michal Nowicki, Ivan Rybalko, Kyi Min Thant | AGH- WIMIR MEI Rev 24.04.2025 Bone Container 2 Date of Issue Scale 1

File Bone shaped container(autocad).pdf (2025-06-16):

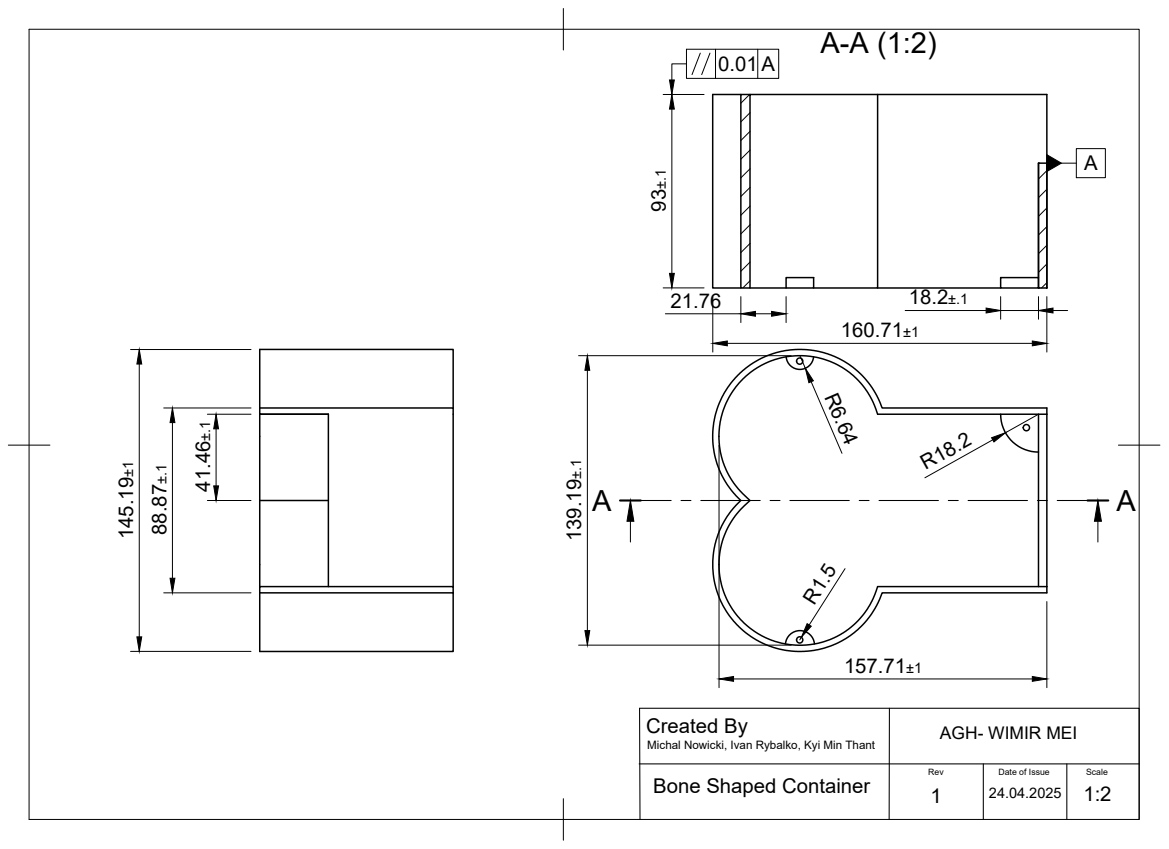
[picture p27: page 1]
AGH- WIMIR MEI Rev; Date of Issue; Scale 1 Bone Shaped Container

Created By Michal Nowicki, Ivan Rybalko, Kyi Min Thant

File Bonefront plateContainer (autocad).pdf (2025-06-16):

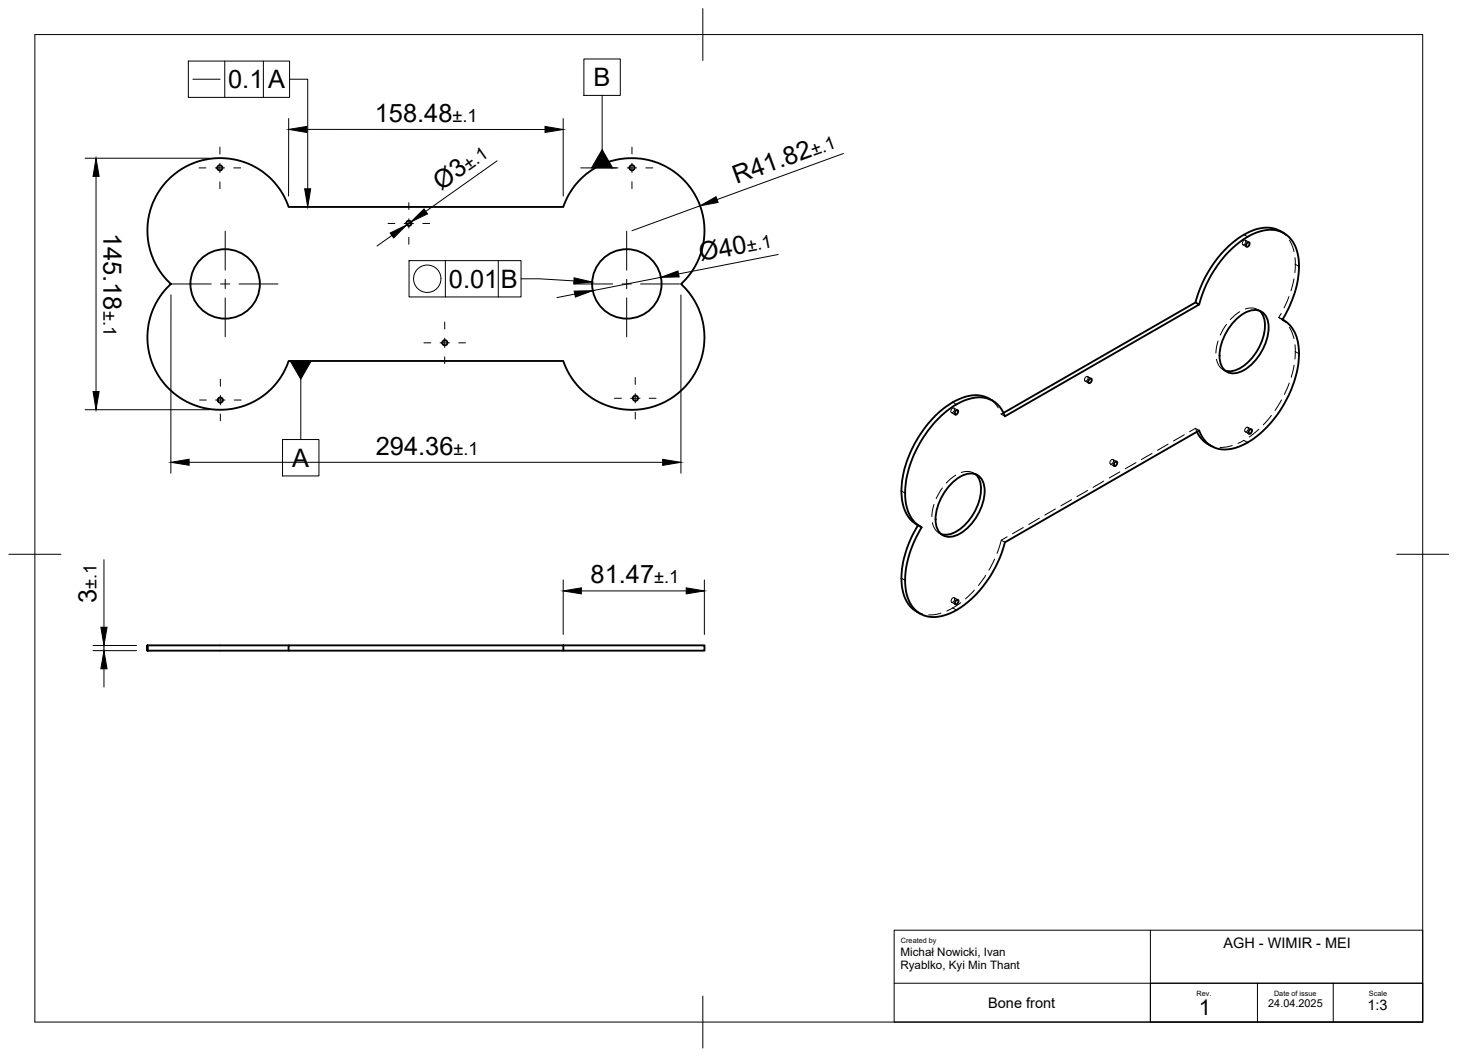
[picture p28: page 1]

Created by Michał Nowicki, Ivan Ryablko, Kyi Min Thant | AGH - WIMIR - MEI Rev. 1

Bone front | | Date of issue 24.04.2025 | Scale 1:3

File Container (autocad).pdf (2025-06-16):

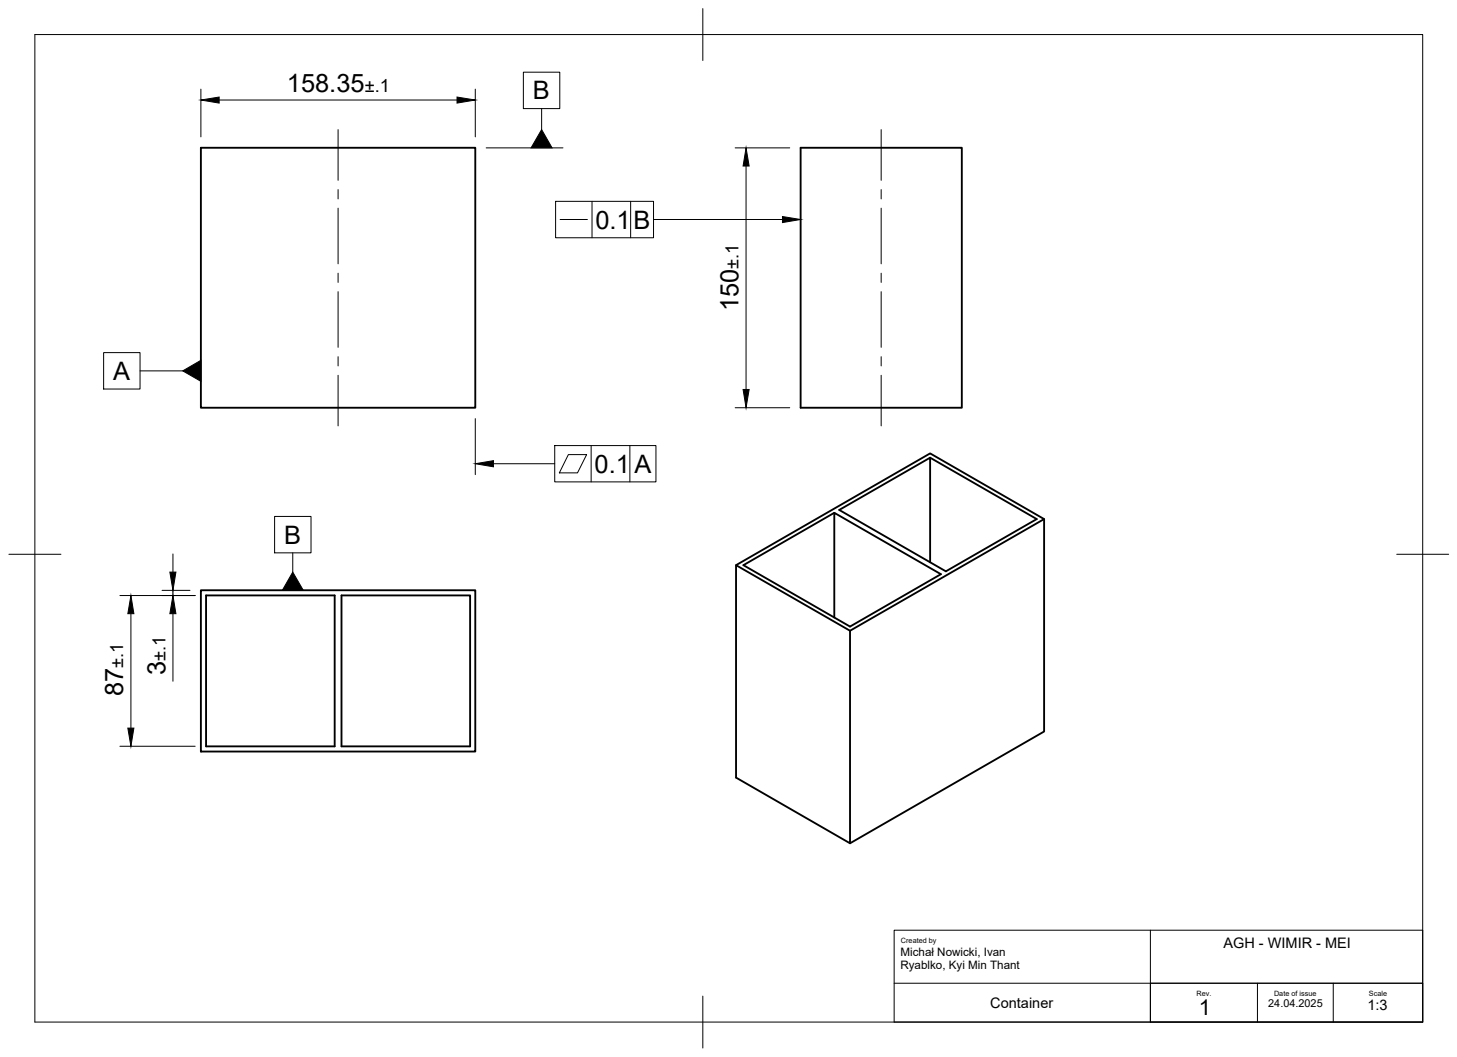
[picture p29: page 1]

Created by Michał Nowicki, Ivan Ryablko, Kyi Min Thant | AGH - WIMIR - MEI Rev. 1

Container | | Date of issue 24.04.2025 | Scale 1:3

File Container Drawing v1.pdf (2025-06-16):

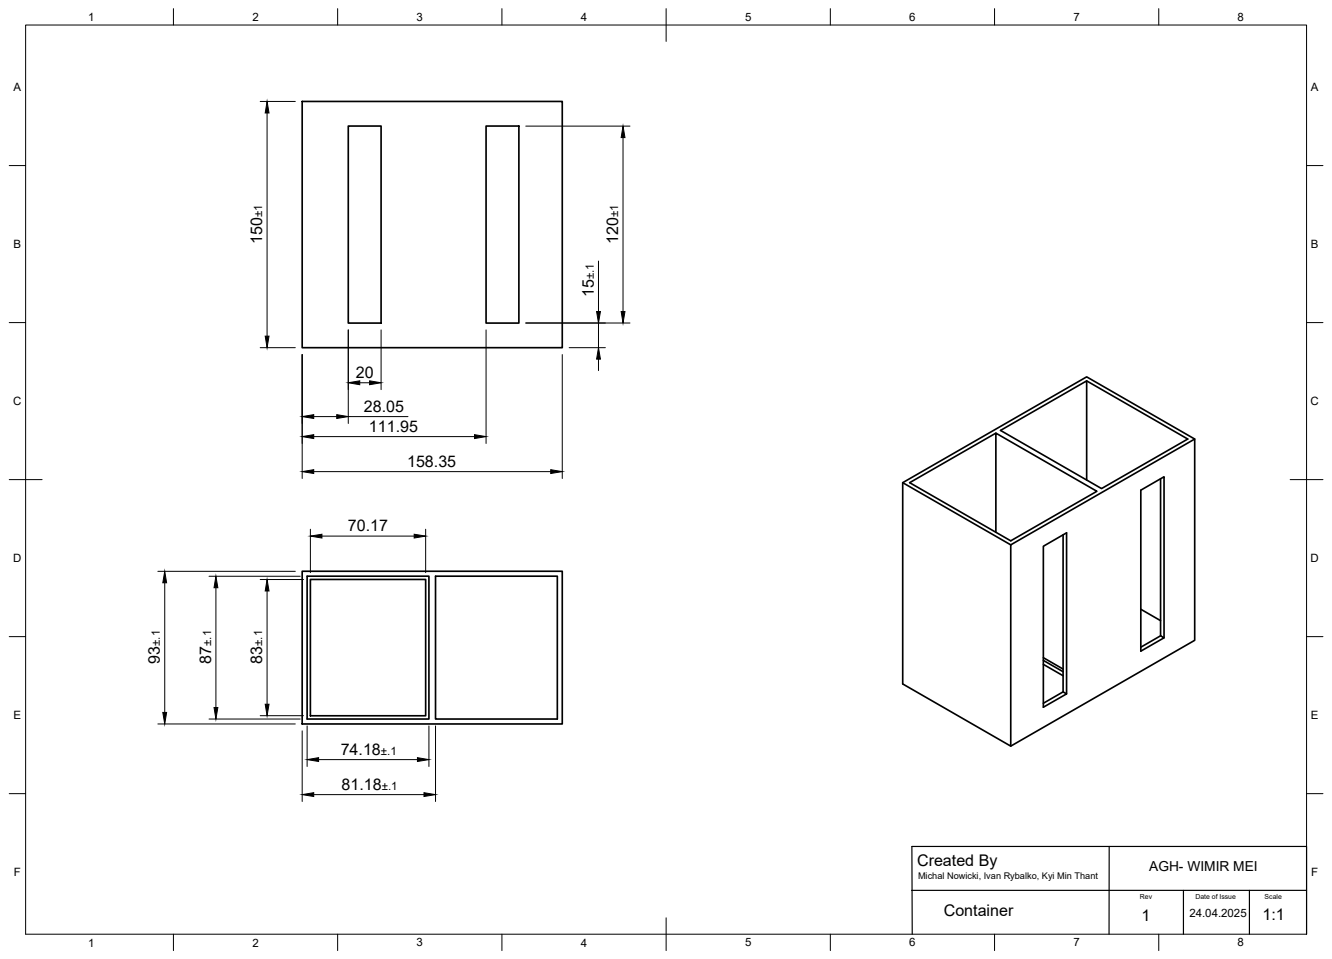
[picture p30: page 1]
Created By; AGH- WIMIR MEI Rev; Date of Issue; Scale Container

Michal Nowicki, Ivan Rybalko, Kyi Min Thant
